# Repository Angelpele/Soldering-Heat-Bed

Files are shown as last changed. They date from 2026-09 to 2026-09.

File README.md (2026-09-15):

# PCB Heated Soldering Bed

<p align="center">
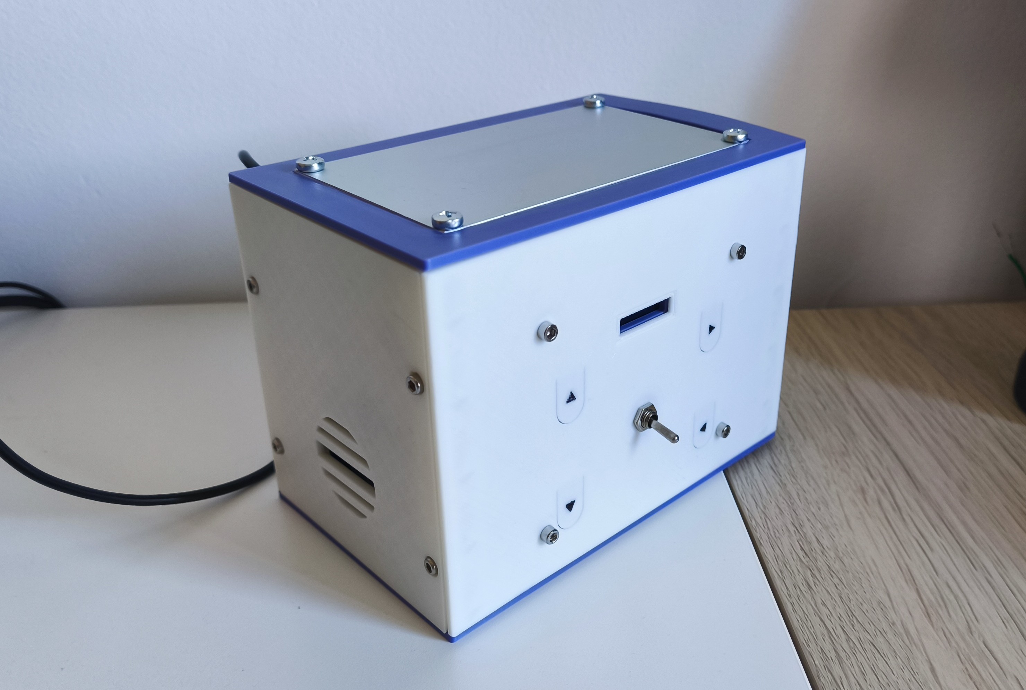
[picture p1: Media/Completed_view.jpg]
Finished heated soldering bed
  
</p>

Custom PCB based heating bed for PCB assembly and solder reflow.

The system uses an Arduino Nano to control a relay that powers a resistive heating plate, monitor temperature with an NTC thermistor, control a cooling fan, and provide a simple OLED interface.

Different buttons provide the user an easy way to navigate through the different menus available in the screen. The reflow profile can be modified, create a new one, power the fan or leave it in automatic mode... The main lever powers the heating element, initiating the reflow process. 

To avoid melting the internals, the heating element was secured with 4 x M4 bolts capable of disipating the heat to the lower part of the assembly. The main structure consists of 6 panels total, secured together with screws and threaded inserts.

---

## Features

| Feature | Description |
|---|---|
| Controller | Arduino Nano |
| Heater | 220 V heating element |
| Temperature sensor | NTC thermistor |
| Heater control | Relay |
| Cooling | 12 V fan + N-MOSFET |
| Display | 0.91" 128×32 I2C OLED |
| User input | 4 buttons + safety lever |
| Audio | Buzzer |
| Modes | Manual heating / Reflow |
| Reflow profile | Sn63Pb37 |
| Temperature range | 30–230 °C |
| Temperature ramp | 1 °C/s |

---

## Hardware

### Components

| Component | Reference | Specification |
|---|---|---|
| Arduino Nano | U101 | Main controller |
| Heating element | Heater | 12 V |
| Relay | R101 | 5 V |
| NTC thermistor | TH101 | Temperature measurement |
| MOSFET | Q101 | N-channel |
| Fan | M101 | 12 V |
| OLED | OLED_0.91 | 128×32, I2C |
| Buzzer | BZ101 | Audio indication |
| Transformer | T1 | 220 V AC → 12 V |
| Main switch | SW1 | Power switch |
| BUT1–BUT4 | — | User controls |
| LEVER | — | Safety input |
| R101 | — | 100 kΩ |
| R102 | — | 100 Ω |
| R103 | — | 1 kΩ |
| R104 | — | — |

---

## Schematic & Wiring

<table>
<tr>
<td width="50%" align="center" valign="top">

<b>Schematic</b><br><br>

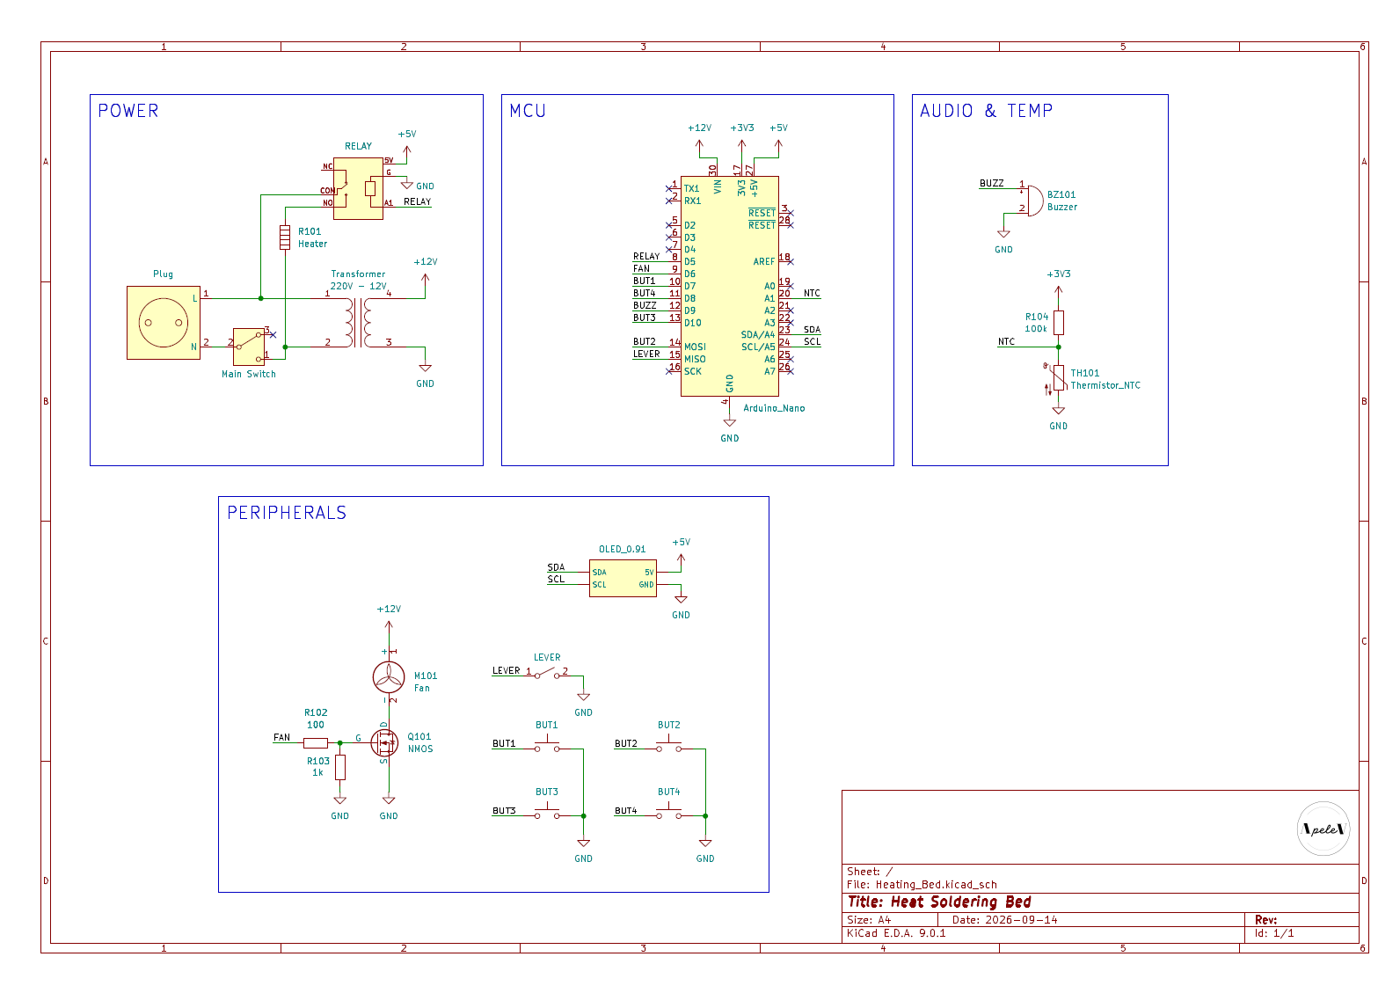
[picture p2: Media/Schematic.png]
Heating bed schematic


</td>

<td width="50%" align="center" valign="top">

<b>Internals / Wiring</b><br><br>

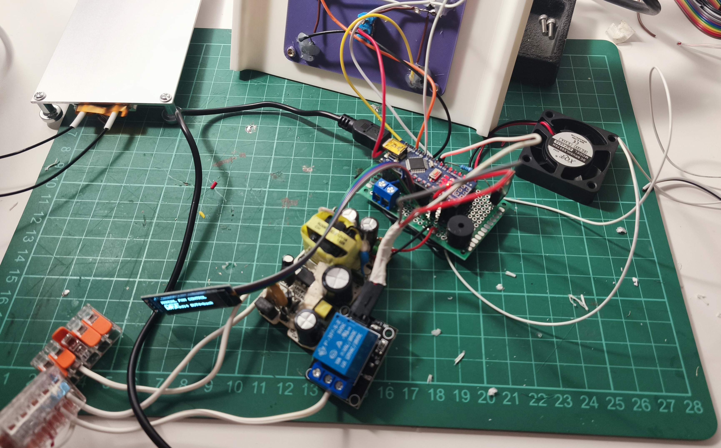
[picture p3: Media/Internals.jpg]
Heating bed wiring


</td>
</tr>
</table>

---

## Reflow Profile

| Stage | Target | Duration |
|---|---:|---:|
| Stage 1 | 150 °C | 60 s |
| Stage 2 | 180 °C | 60 s |
| Stage 3 | 210 °C | 30 s |

Setpoint ramp: **1 °C/s**

---

## Reflow Test

<p align="center">
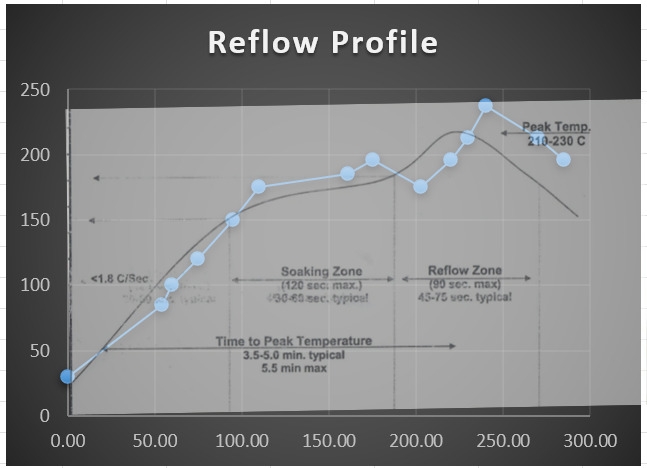
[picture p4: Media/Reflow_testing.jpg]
Theoretical vs real reflow temperature profile
  
</p>

| Profile | Description |
|---|---|
| Theory | Target temperature profile |
| Real | Temperature measured during the test |

The difference is mainly caused by thermal inertia, heater power, heat losses, sensor position, and control response.

---

## Temperature Control

| Parameter | Value |
|---|---:|
| Series resistor | 100 kΩ |
| Nominal resistance | 75 kΩ |
| Nominal temperature | 20 °C |
| Beta coefficient | 4092 |

```cpp
const float SERIES_RESISTOR      = 100000.0;
const float NOMINAL_RESISTANCE   = 75000.0;
const float NOMINAL_TEMPERATURE  = 20.0;
const float B_COEFFICIENT        = 4092.0;

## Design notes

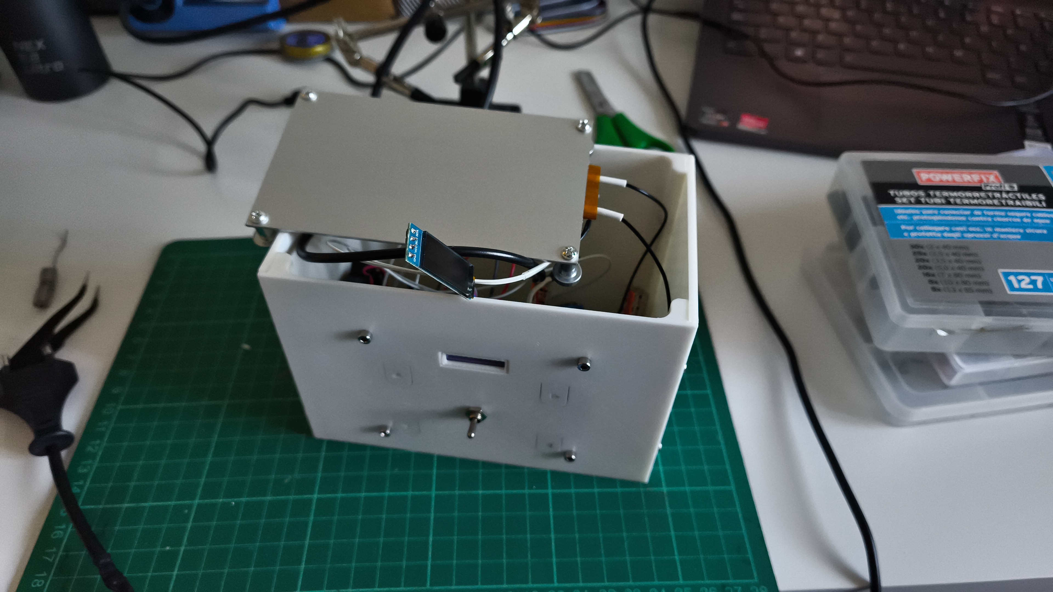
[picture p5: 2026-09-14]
Media/Top_opened.jpeg

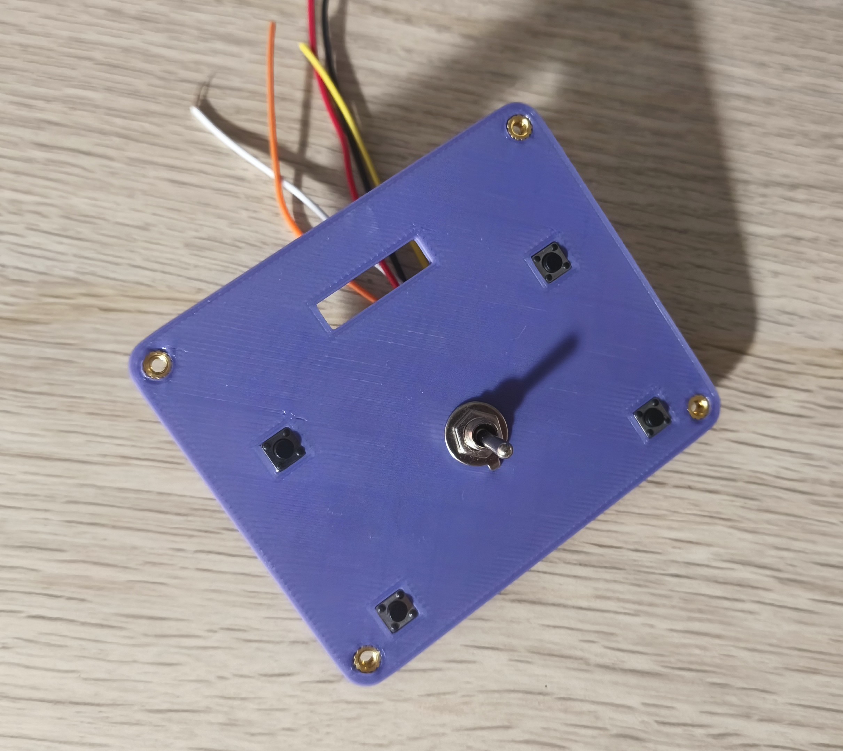
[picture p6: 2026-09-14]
Media/Button_panel.jpg

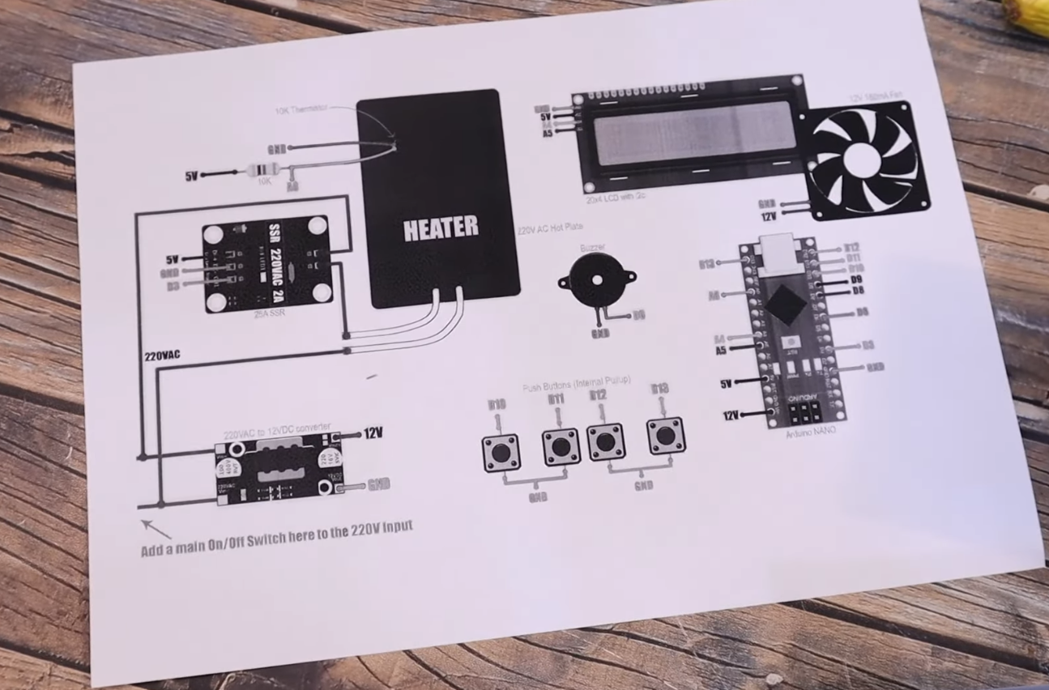
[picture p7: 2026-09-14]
Media/Screenshot 2026-09-02 192525.png

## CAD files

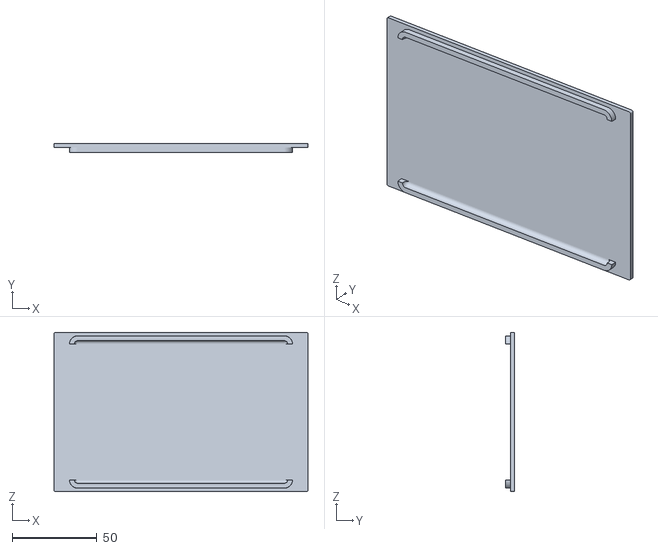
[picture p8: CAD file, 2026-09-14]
Mechanical/Bottom Plate v3.stl
150.0 x 5.50 x 94.2

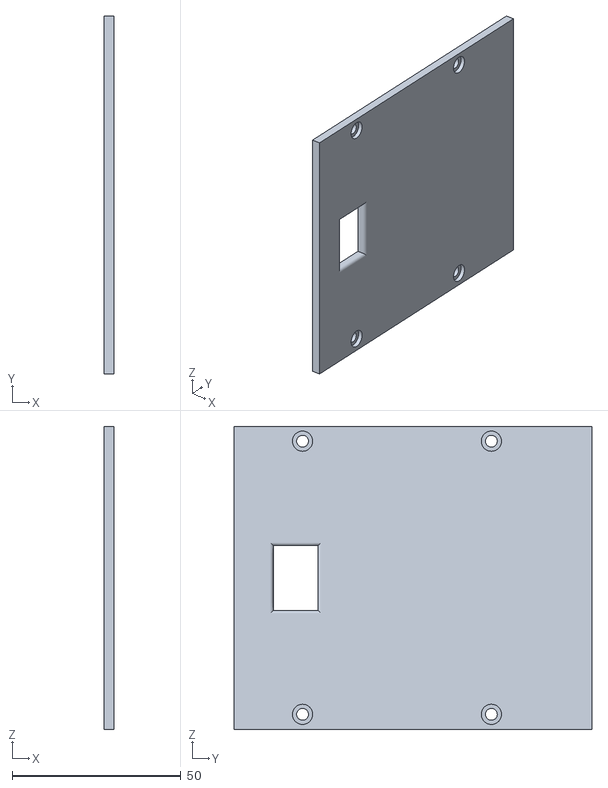
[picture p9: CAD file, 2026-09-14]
Mechanical/Side Wall v6.stl
3.00 x 106.1 x 89.8

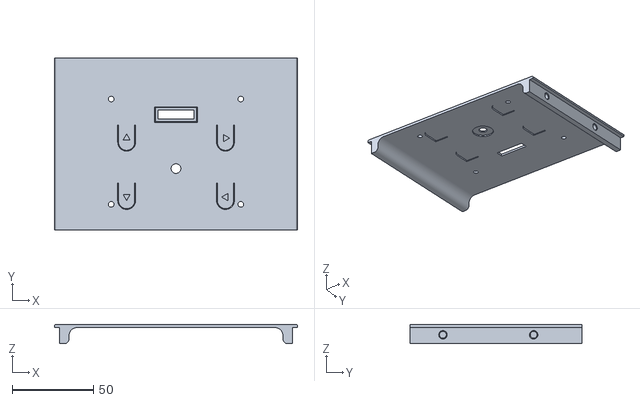
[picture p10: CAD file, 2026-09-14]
Mechanical/Front Wall.stl
150.0 x 106.1 x 12.0

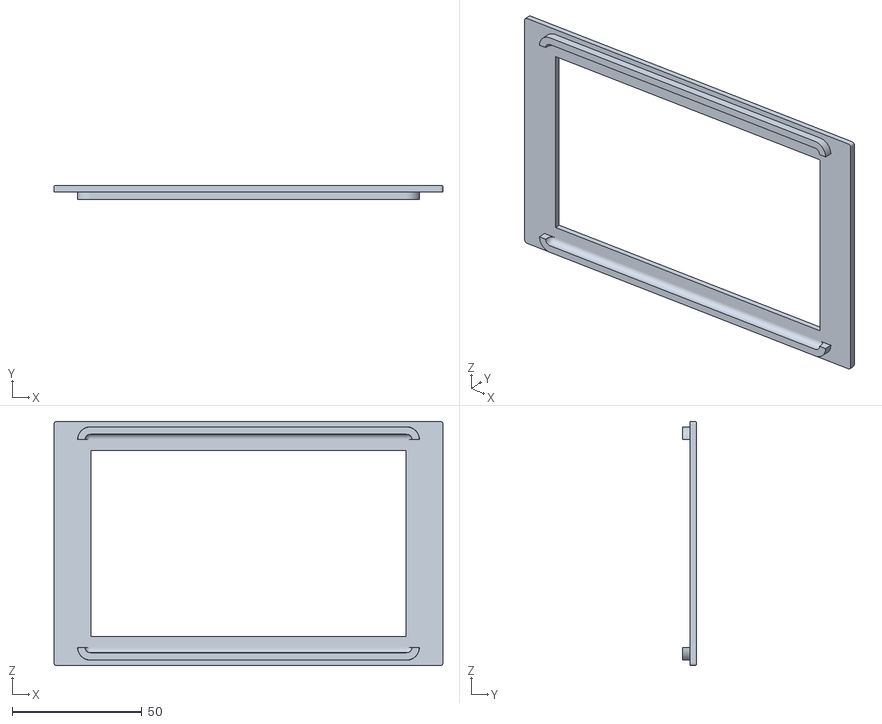
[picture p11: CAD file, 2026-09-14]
Mechanical/Top Cover v6.stl
150.0 x 5.50 x 94.2

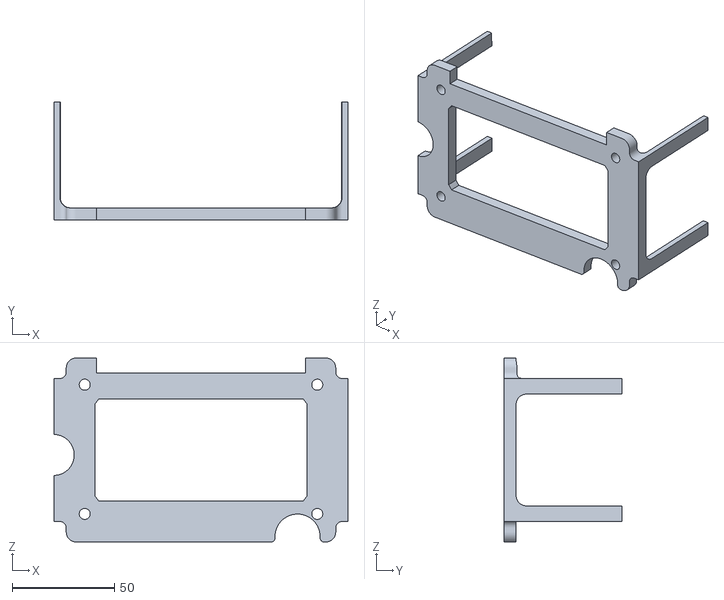
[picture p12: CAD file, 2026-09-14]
Mechanical/Middle_Plate.stl
143.7 x 57.8 x 90.0

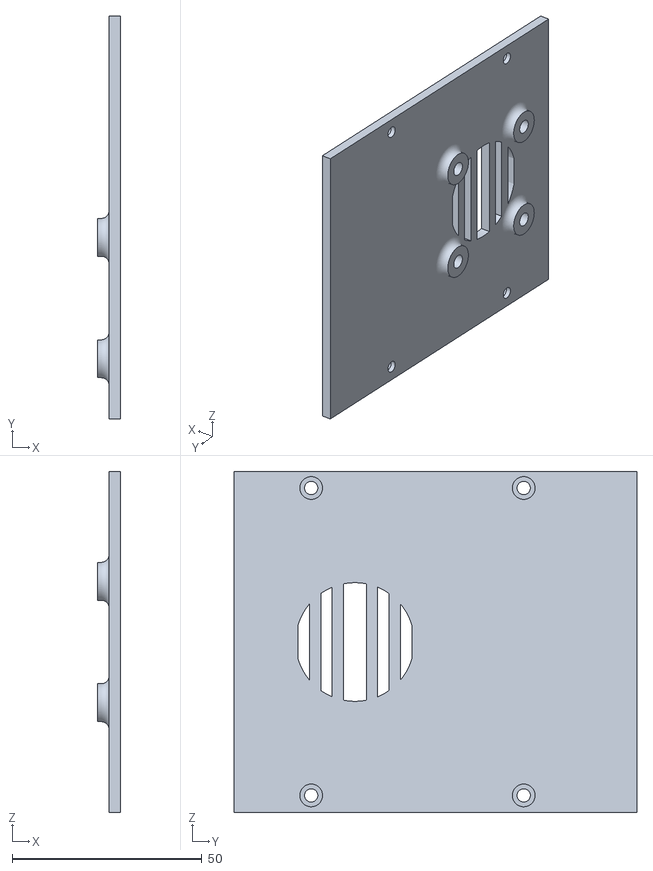
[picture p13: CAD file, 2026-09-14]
Mechanical/Side Wall Fan v3.stl
6.00 x 106.1 x 89.8

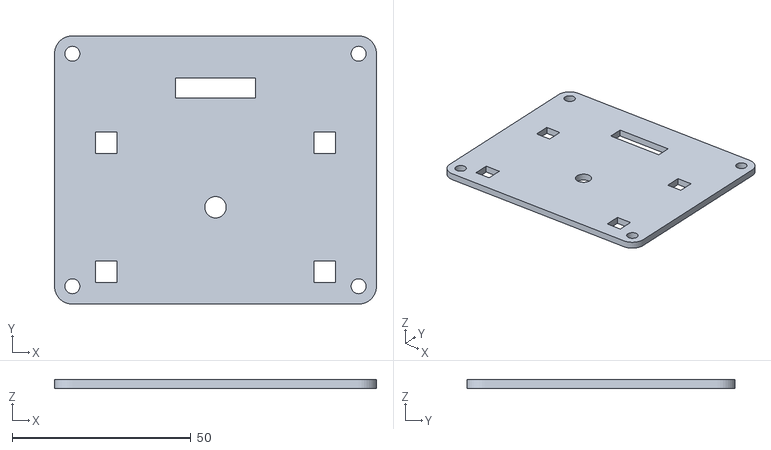
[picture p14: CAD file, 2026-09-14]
Mechanical/Button_Panel.stl
90.0 x 75.0 x 2.50

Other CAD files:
Mechanical/Back Wall v6.stl

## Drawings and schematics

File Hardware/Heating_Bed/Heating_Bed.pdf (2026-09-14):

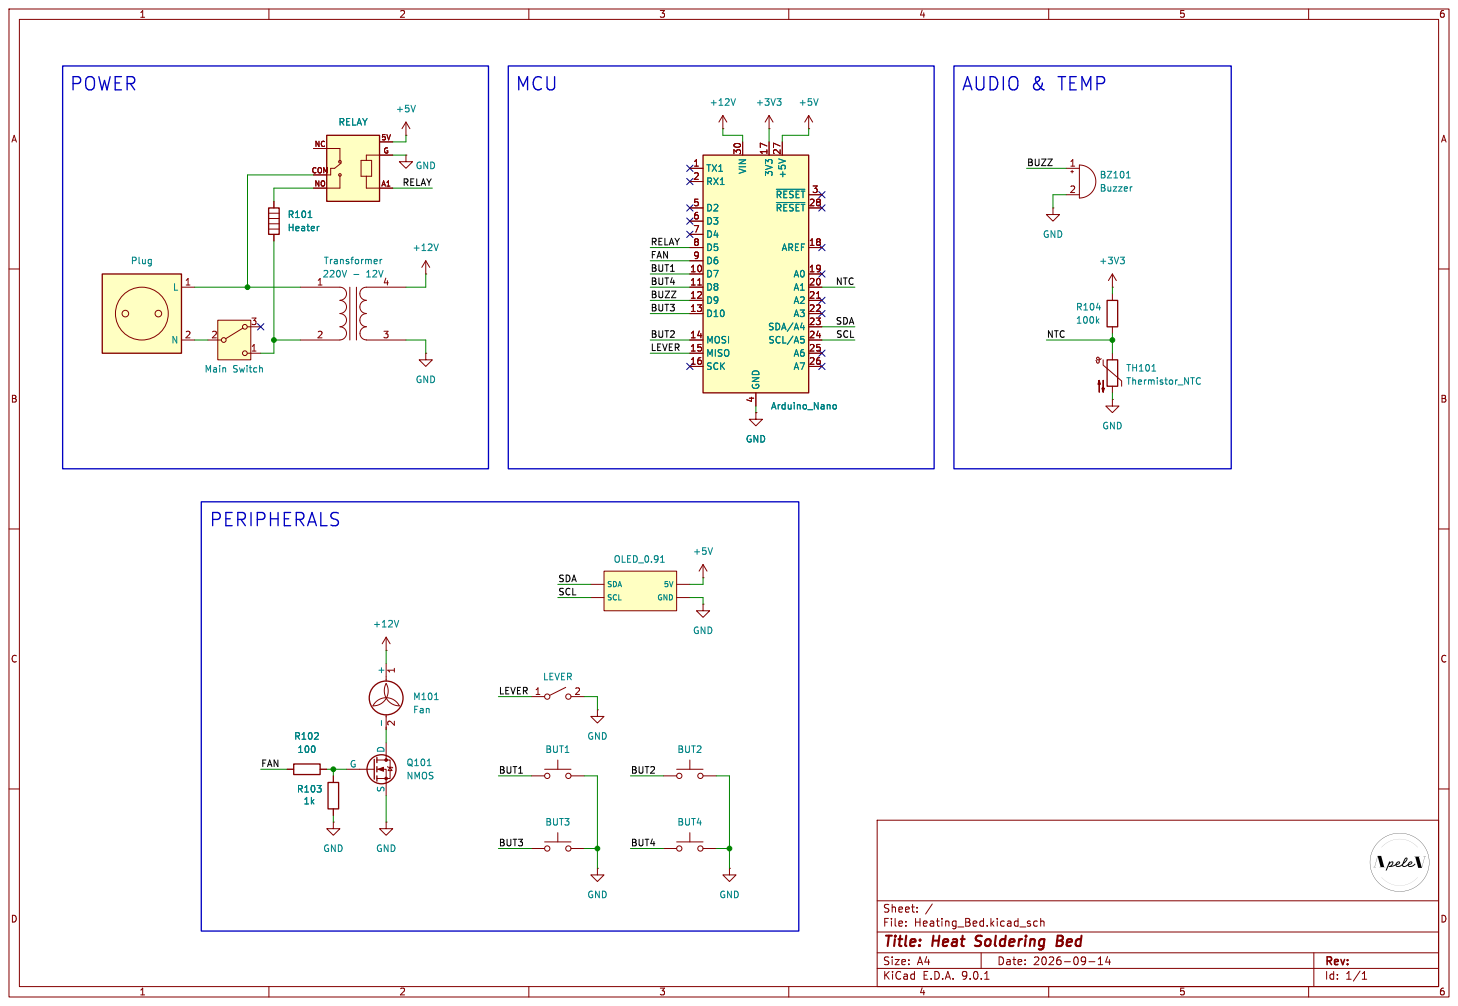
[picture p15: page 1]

File: Heating_Bed.kicad_sch Sheet: /
Id: 1/1 Title: Heat Soldering Bed

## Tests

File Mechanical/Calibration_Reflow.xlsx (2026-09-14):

Time | Temperature
0.00 | 30
54.00 | 85
60.00 | 100
75.00 | 120
95.00 | 150
110.00 | 175
161.00 | 185
175.00 | 196
203.00 | 175
220.00 | 196
230.00 | 213
240.00 | 237
270.00 | 213
285.00 | 196
297.00 | 185
311.00 | 175
320.00 | 168
337.00 | 156
354.00 | 147
372.00 | 140
382.00 | 134
392.00 | 129
404.00 | 124
453.00 | 115
480.00 | 100

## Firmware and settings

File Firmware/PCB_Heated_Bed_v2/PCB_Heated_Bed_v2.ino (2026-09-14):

#include <Wire.h>
#include <Adafruit_GFX.h>
#include <Adafruit_SSD1306.h>
#include <EEPROM.h>

// =====================================================
// PINS
// =====================================================

#define FAN_PIN     6
#define RELAY_PIN   5
#define BUZZER_PIN  9
#define BUT1_PIN    7
#define BUT2_PIN    11
#define BUT3_PIN    10
#define BUT4_PIN    8
#define LEVER_PIN   12

#define THERMISTOR_PIN A1

// OLED 0.91" -> 128x32
#define SCREEN_WIDTH  128
#define SCREEN_HEIGHT 32

#define OLED_RESET    -1
#define OLED_ADDRESS  0x3C

Adafruit_SSD1306 display(SCREEN_WIDTH, SCREEN_HEIGHT, &Wire, OLED_RESET);

// =====================================================
// THERMISTOR (NTC) CONFIG
// =====================================================

const float SERIES_RESISTOR      = 100000.0; // Ohms
const float NOMINAL_RESISTANCE   = 75000.0; // Ohms at 30C
const float NOMINAL_TEMPERATURE  = 20.0;    // C
const float B_COEFFICIENT        = 4092.0;
const int   ADC_MAX              = 1023;

// =====================================================
// GENERAL CONFIG
// =====================================================

const unsigned long DEBOUNCE_DELAY   = 30;    // ms
const unsigned long BUZZER_TIME      = 100;   // ms beep length
const unsigned long WARNING_TIME     = 5000;  // ms lever-on warning before heating

const int MIN_TARGET_TEMP = 30;
const int MAX_TARGET_TEMP = 230;

// =====================================================
// TIME-PROPORTIONING & RAMP CONTROL (OVERSHOOT FIX)
// =====================================================

const unsigned long HEAT_WINDOW_MS = 4000;  // length of one PWM cycle
const float HEAT_DUTY_MAX  = 0.35f;         // REDUCED: hard cap on ON-fraction due to huge thermal mass
const float HEAT_PROP_BAND = 30.0f;         // INCREASED: tapers off heat earlier to prevent overshoot

// Ramping restricts how fast the target temperature climbs so the thermistor can keep up
const float RAMP_RATE_C_PER_SEC = 1.0f;     // Complies with the <1.8 C/Sec limit on the graph

unsigned long heatWindowStart = 0;
unsigned long heatOnTime      = 0;
unsigned long lastRampTime    = 0;
float dynamicSetpoint         = 25.0f;      // Slowly climbs to the actual target

// =====================================================
// REFLOW PROFILE DATA
// =====================================================

struct ProfileStage {
  int targetTemp; // C
  int duration;   // seconds, 0 = hold indefinitely
};

#define MAX_STAGES 3

bool isReflowProfile = false;
int currentProfileStages = 1;
int currentStageIndex = 0;
ProfileStage activeProfile[MAX_STAGES];

// Based on the handwritten notes and Kester graph
const ProfileStage KESTER_PROFILE[MAX_STAGES] = {
  { 150, 60 },  // Preheat / Soak Start
  { 180, 60 },  // Soak End (Notes say ~58s)
  { 210, 30 }   // Reflow Peak
};

// =====================================================
// EEPROM DATA
// =====================================================

struct Settings {
  uint8_t  magic;
  int      targetTemp; // Saved manual bake temperature
};

const uint8_t SETTINGS_MAGIC = 0xA6; // Changed to force reset with new struct
Settings settings;

// =====================================================
// INPUT DEBOUNCING (buttons + lever)
// =====================================================

struct DebouncedInput {
  uint8_t pin;
  bool activeLow;
  bool stableState;
  bool lastReading;
  unsigned long lastChangeTime;
};

DebouncedInput but1  = { BUT1_PIN,  true,  false, false, 0 };
DebouncedInput but2  = { BUT2_PIN,  true,  false, false, 0 };
DebouncedInput but3  = { BUT3_PIN,  true,  false, false, 0 };
DebouncedInput but4  = { BUT4_PIN,  true,  false, false, 0 };
DebouncedInput lever = { LEVER_PIN, false, false, false, 0 };

bool updateInput(DebouncedInput &in) {
  bool raw = digitalRead(in.pin);
  bool reading = in.activeLow ? !raw : raw;

  if (reading != in.lastReading) {
    in.lastChangeTime = millis();
  }

  bool changed = false;
  if ((millis() - in.lastChangeTime) > DEBOUNCE_DELAY) {
    if (reading != in.stableState) {
      in.stableState = reading;
      changed = true;
    }
  }

  in.lastReading = reading;
  return changed;
}

// =====================================================
// UI STATE MACHINE
// =====================================================

enum UIState {
  UI_TOP,
  UI_FAN_EDIT,
  UI_TEMP_EDIT
};

enum TopScreen {
  SCREEN_HOME = 0,
  SCREEN_FAN,
  SCREEN_TEMP,
  SCREEN_REFLOW,
  SCREEN_COUNT
};

UIState  uiState    = UI_TOP;
int      screenIndex = SCREEN_HOME;

enum FanMode { FAN_AUTO = 0, FAN_FORCED_ON, FAN_FORCED_OFF };
const char *fanModeName(FanMode m);

FanMode fanMode = FAN_AUTO;
FanMode fanModeEditBuffer = FAN_AUTO;
int tempEditBuffer = 50;

// =====================================================
// BED (RELAY) CONTROL STATE MACHINE
// =====================================================

enum BedState { BED_IDLE, BED_WARNING, BED_RAMPING, BED_SOAKING, BED_COOLING, BED_DONE };
BedState bedState = BED_IDLE;

unsigned long warningStartTime = 0;
unsigned long soakStartTime    = 0;
int  lastWarningBeepSecond = -1;

bool fanOnState   = false;
bool relayOnState = false;
float currentTempC = 25.0;

// =====================================================
// NON-BLOCKING BUZZER
// =====================================================

bool buzzerActive = false;
unsigned long buzzerOffTime = 0;

void buzzerStart(unsigned long durationMs) {
  analogWrite(BUZZER_PIN, 128);
  buzzerActive = true;
  buzzerOffTime = millis() + durationMs;
}

void buzzerUpdate() {
  if (buzzerActive && millis() >= buzzerOffTime) {
    analogWrite(BUZZER_PIN, 0);
    buzzerActive = false;
  }
}

// =====================================================
// EEPROM HELPERS
// =====================================================

void loadDefaultSettings() {
  settings.magic = SETTINGS_MAGIC;
  settings.targetTemp = 60; // Safe default for manual mode
}

void loadSettings() {
  EEPROM.get(0, settings);
  if (settings.magic != SETTINGS_MAGIC ||
      settings.targetTemp < MIN_TARGET_TEMP ||
      settings.targetTemp > MAX_TARGET_TEMP) {
    loadDefaultSettings();
    EEPROM.put(0, settings);
  }
}

void saveSettings() {
  EEPROM.put(0, settings);
}

// =====================================================
// THERMISTOR READING
// =====================================================

float readTemperatureC() {
  int raw = analogRead(THERMISTOR_PIN);
  if (raw <= 0) raw = 1;
  if (raw >= ADC_MAX) raw = ADC_MAX - 1;

  float resistance = SERIES_RESISTOR / ((float)ADC_MAX / raw - 1.0);
  float steinhart = resistance / NOMINAL_RESISTANCE;
  steinhart = log(steinhart);
  steinhart /= B_COEFFICIENT;
  steinhart += 1.0 / (NOMINAL_TEMPERATURE + 273.15);
  steinhart = 1.0 / steinhart;
  steinhart -= 273.15;
  return steinhart;
}

// =====================================================
// ACTUATORS
// =====================================================

void setFan(bool on) {
  fanOnState = on;
  digitalWrite(FAN_PIN, on ? HIGH : LOW);
}

void setRelay(bool on) {
  relayOnState = on;
  digitalWrite(RELAY_PIN, on ? HIGH : LOW);
}

void updateFanControl() {
  switch (fanMode) {
    case FAN_FORCED_ON:  setFan(true); break;
    case FAN_FORCED_OFF: setFan(false); break;
    case FAN_AUTO:
    default:
      // Auto fan logic during cooling or if current temp is highly over target
      if (bedState == BED_COOLING) {
          setFan(true);
      } else if (bedState == BED_IDLE || bedState == BED_DONE) {
          setFan(currentTempC > 50.0);
      } else {
          setFan(false); // keep fan off while actively heating
      }
      break;
  }
}

// =====================================================
// PROFILE ACTIVATION
// =====================================================

void applyManualTarget(int newTargetTemp) {
  currentProfileStages = 1;
  activeProfile[0] = { newTargetTemp, 0 }; // 0 duration = hold indefinitely
  isReflowProfile = false;
  bedState = BED_IDLE;
}

void applyReflowProfile() {
  currentProfileStages = MAX_STAGES;
  for(int i=0; i<MAX_STAGES; i++) {
    activeProfile[i] = KESTER_PROFILE[i];
  }
  isReflowProfile = true;
  bedState = BED_IDLE;
}

// =====================================================
// CONTROL LOGIC (WITH SETPOINT RAMPING)
// =====================================================

void updateHeatOutput(float targetTemp) {
  unsigned long now = millis();
  unsigned long elapsedInWindow = now - heatWindowStart;

  if (elapsedInWindow >= HEAT_WINDOW_MS) {
    float error = targetTemp - currentTempC;
    // Duty cycle calculation
    float duty = constrain(error / HEAT_PROP_BAND, 0.0f, 1.0f) * HEAT_DUTY_MAX;
    heatOnTime = (unsigned long)(duty * HEAT_WINDOW_MS);
    heatWindowStart = now;
    elapsedInWindow = 0;
  }

  setRelay(elapsedInWindow < heatOnTime);
}

void updateBedControl() {
  bool leverChanged = updateInput(lever);
  (void)leverChanged;

  if (!lever.stableState) {
    if (bedState != BED_IDLE) {
      setRelay(false);
      bedState = BED_IDLE;
    }
    return;
  }

  switch (bedState) {

    case BED_IDLE:
      bedState = BED_WARNING;
      warningStartTime = millis();
      lastWarningBeepSecond = -1;
      break;

    case BED_WARNING: {
      unsigned long elapsed = millis() - warningStartTime;
      int currentSecond = elapsed / 1000;
      if (currentSecond != lastWarningBeepSecond) {
        lastWarningBeepSecond = currentSecond;
        buzzerStart(BUZZER_TIME);
      }
      if (elapsed >= WARNING_TIME) {
        bedState = BED_RAMPING;
        currentStageIndex = 0;
        dynamicSetpoint = currentTempC; // Initialize soft-start at current room temp
        lastRampTime = millis();
        heatWindowStart = millis();
      }
      break;
    }

    case BED_RAMPING: {
      // 1. Advance the dynamic setpoint (Soft Start)
      unsigned long now = millis();
      float dt_sec = (now - lastRampTime) / 1000.0f;
      lastRampTime = now;
      
      dynamicSetpoint += RAMP_RATE_C_PER_SEC * dt_sec;
      
      int stageTarget = activeProfile[currentStageIndex].targetTemp;
      if (dynamicSetpoint > stageTarget) {
        dynamicSetpoint = stageTarget; // Cap at the target for this stage
      }

      // 2. Control heat based on the *dynamic* setpoint, not the final target
      updateHeatOutput(dynamicSetpoint);

      // 3. Move to soak when actual temperature reaches the stage target
      if (currentTempC >= stageTarget) {
        if (activeProfile[currentStageIndex].duration > 0) {
          bedState = BED_SOAKING;
          soakStartTime = millis();
        } else {
          // If duration is 0 (Manual mode), stay in ramping/holding indefinitely
          dynamicSetpoint = stageTarget; 
        }
      }
      break;
    }

    case BED_SOAKING:
      // Hold exactly at the stage target
      updateHeatOutput(activeProfile[currentStageIndex].targetTemp);

      if (millis() - soakStartTime >= (unsigned long)activeProfile[currentStageIndex].duration * 1000UL) {
        currentStageIndex++;
        if (currentStageIndex >= currentProfileStages) {
          bedState = BED_COOLING; // All stages complete
        } else {
          bedState = BED_RAMPING; // Move to next heating stage
          lastRampTime = millis();
        }
      }
      break;

    case BED_COOLING:
      setRelay(false);
      if (currentTempC <= 50.0) {
        bedState = BED_DONE;
        buzzerStart(500); // Long beep to indicate done
      }
      break;

    case BED_DONE:
      setRelay(false);
      break;
  }
}

// =====================================================
// BUTTON HANDLING / NAVIGATION
// =====================================================

void handleTopNavigation(bool p1, bool p2, bool p3, bool p4) {
  if (p1) screenIndex = (screenIndex + SCREEN_COUNT - 1) % SCREEN_COUNT;
  if (p2) screenIndex = (screenIndex + 1) % SCREEN_COUNT;

  if (p3) {
    switch (screenIndex) {
      case SCREEN_FAN:
        fanModeEditBuffer = fanMode;
        uiState = UI_FAN_EDIT;
        break;
      case SCREEN_TEMP:
        tempEditBuffer = settings.targetTemp;
        uiState = UI_TEMP_EDIT;
        break;
      case SCREEN_REFLOW:
        applyReflowProfile(); // Instantly selects the reflow profile
        buzzerStart(BUZZER_TIME);
        screenIndex = SCREEN_HOME;
        break;
      case SCREEN_HOME:
      default:
        break; 
    }
  }

  if (p4) {
    screenIndex = SCREEN_HOME;
  }
}

void handleFanEdit(bool p1, bool p2, bool p3, bool p4) {
  if (p1) fanModeEditBuffer = (FanMode)((fanModeEditBuffer + 1) % 3);
  if (p2) fanModeEditBuffer = (FanMode)((fanModeEditBuffer + 2) % 3);
  if (p3) {
    fanMode = fanModeEditBuffer;
    buzzerStart(BUZZER_TIME);
    uiState = UI_TOP;
  }
  if (p4) uiState = UI_TOP;
}

void handleTempEdit(bool p1, bool p2, bool p3, bool p4) {
  if (p1) tempEditBuffer = min(tempEditBuffer + 1, MAX_TARGET_TEMP);
  if (p2) tempEditBuffer = max(tempEditBuffer - 1, MIN_TARGET_TEMP);
  if (p3) {
    settings.targetTemp = tempEditBuffer;
    saveSettings();
    applyManualTarget(settings.targetTemp); // Sets manual mode
    buzzerStart(BUZZER_TIME);
    uiState = UI_TOP;
  }
  if (p4) uiState = UI_TOP;
}

void handleButtons() {
  bool c1 = updateInput(but1);
  bool c2 = updateInput(but2);
  bool c3 = updateInput(but3);
  bool c4 = updateInput(but4);

  bool p1 = c1 && but1.stableState;
  bool p2 = c2 && but2.stableState;
  bool p3 = c3 && but3.stableState;
  bool p4 = c4 && but4.stableState;

  if (!(p1 || p2 || p3 || p4)) return;

  switch (uiState) {
    case UI_TOP:       handleTopNavigation(p1, p2, p3, p4); break;
    case UI_FAN_EDIT:  handleFanEdit(p1, p2, p3, p4);       break;
    case UI_TEMP_EDIT: handleTempEdit(p1, p2, p3, p4);      break;
  }
}

// =====================================================
// DISPLAY
// =====================================================

const char *fanModeName(FanMode m) {
  switch (m) {
    case FAN_FORCED_ON:  return "ON";
    case FAN_FORCED_OFF: return "OFF";
    case FAN_AUTO:
    default:              return "AUTO";
  }
}

void drawLogo() {
  display.clearDisplay();
  display.setTextColor(SSD1306_WHITE);
  display.drawRect(2, 2, SCREEN_WIDTH - 4, SCREEN_HEIGHT - 4, SSD1306_WHITE);
  display.setTextSize(1);
  display.setCursor(14, 4);
  display.print("PCB HEATED BED");
  display.setCursor(30, 18);
  display.print("v3  booting...");
  display.display();
}

void drawHome() {
  display.drawRoundRect(0, 0, SCREEN_WIDTH, SCREEN_HEIGHT, 4, SSD1306_WHITE);

  display.setTextSize(1);
  display.setCursor(8, 3);
  
  // Show Current Mode and Status
  if (isReflowProfile) {
    if (bedState == BED_RAMPING)        display.print("REFLOW: RAMPING");
    else if (bedState == BED_SOAKING)   display.print("REFLOW: SOAKING");
    else if (bedState == BED_COOLING)   display.print("REFLOW: COOLING");
    else if (bedState == BED_DONE)      display.print("REFLOW: DONE");
    else                                display.print("READY: REFLOW SOLDER");
  } else {
    display.print("READY: MANUAL BAKE");
  }
  display.drawFastHLine(6, 12, SCREEN_WIDTH - 12, SSD1306_WHITE);

  char buf[8];
  dtostrf(currentTempC, 4, 1, buf);
  display.setTextSize(2);
  display.setCursor(28, 16);
  display.print(buf);
  display.print("C");
}

void drawFanScreen() {
  display.setCursor(0, 0);
  display.print("MANUAL FAN CONTROL");
  display.setCursor(0, 8);
  display.setTextSize(2);
  display.print(fanModeName(fanMode));
  display.setTextSize(1);
  display.setCursor(0, 24);
  display.print("BUT3=edit BUT4=back");
}

void drawFanEditScreen() {
  display.setCursor(0, 0);
  display.print("SET FAN MODE");
  display.setCursor(0, 8);
  display.setTextSize(2);
  display.print(fanModeName(fanModeEditBuffer));
  display.setTextSize(1);
  display.setCursor(0, 24);
  display.print("3=OK  4=cancel");
}

void drawTempScreen() {
  display.setCursor(0, 0);
  display.print("MANUAL TARGET TEMP");
  display.setCursor(0, 12);
  display.setTextSize(2);
  display.print(settings.targetTemp);
  display.print("C");
  display.setTextSize(1);
  display.setCursor(70, 20);
  display.print("Now:");
  display.print((int)currentTempC);
}

void drawTempEditScreen() {
  display.setCursor(0, 0);
  display.print("SET MANUAL TEMP");
  display.setCursor(0, 8);
  display.setTextSize(2);
  display.print(tempEditBuffer);
  display.print("C");
  display.setTextSize(1);
  display.setCursor(0, 24);
  display.print("1=+ 2=- 3=OK 4=X");
}

void drawReflowScreen() {
  display.setCursor(0, 0);
  display.print("REFLOW PROFILE");
  display.setCursor(0, 10);
  display.print("Kester Sn63Pb37");
  display.setCursor(0, 24);
  display.print("BUT3=Select BUT4=Back");
}

void updateDisplay() {
  display.clearDisplay();
  display.setTextColor(SSD1306_WHITE);
  display.setTextSize(1);

  if (uiState == UI_TOP) {
    switch (screenIndex) {
      case SCREEN_HOME:   drawHome();        break;
      case SCREEN_FAN:    drawFanScreen();   break;
      case SCREEN_TEMP:   drawTempScreen();  break;
      case SCREEN_REFLOW: drawReflowScreen();break;
    }
  } else {
    switch (uiState) {
      case UI_FAN_EDIT:  drawFanEditScreen();  break;
      case UI_TEMP_EDIT: drawTempEditScreen(); break;
      default: break;
    }
  }

  if (bedState == BED_WARNING) {
    unsigned long remaining = WARNING_TIME - (millis() - warningStartTime);
    unsigned long secondsLeft = (remaining / 1000) + 1;
    char buf[16];
    snprintf(buf, sizeof(buf), "BED ON IN %lus", secondsLeft);

    const int boxX = 4;
    const int boxY = 1;
    const int boxW = SCREEN_WIDTH - (boxX * 2);
    const int boxH = 12;

    display.fillRect(boxX, boxY, boxW, boxH, SSD1306_BLACK);
    display.drawRect(boxX, boxY, boxW, boxH, SSD1306_WHITE);

    int16_t x1, y1;
    uint16_t textW, textH;
    display.setTextSize(1);
    display.getTextBounds(buf, 0, 0, &x1, &y1, &textW, &textH);
    int textX = boxX + (boxW - (int)textW) / 2;
    int textY = boxY + (boxH - (int)textH) / 2 + 1;

    display.setCursor(textX, textY);
    display.print(buf);
  }

  display.display();
}

// =====================================================
// SETUP & LOOP
// =====================================================

void setup() {
  pinMode(FAN_PIN, OUTPUT);
  pinMode(RELAY_PIN, OUTPUT);
  pinMode(BUZZER_PIN, OUTPUT);

  pinMode(BUT1_PIN, INPUT_PULLUP);
  pinMode(BUT2_PIN, INPUT_PULLUP);
  pinMode(BUT3_PIN, INPUT_PULLUP);
  pinMode(BUT4_PIN, INPUT_PULLUP);
  pinMode(LEVER_PIN, INPUT_PULLUP);

  digitalWrite(FAN_PIN, LOW);
  digitalWrite(RELAY_PIN, LOW);
  analogWrite(BUZZER_PIN, 0);

  if (!display.begin(SSD1306_SWITCHCAPVCC, OLED_ADDRESS)) {
    while (true) { digitalWrite(RELAY_PIN, LOW); delay(1000); }
  }

  drawLogo();
  delay(2000);

  loadSettings();
  
  // Default to manual bake state on boot
  applyManualTarget(settings.targetTemp); 
  currentTempC = readTemperatureC();
  updateDisplay();
}

void loop() {
  currentTempC = readTemperatureC();

  handleButtons();
  updateFanControl();
  updateBedControl();
  buzzerUpdate();
  updateDisplay();

  delay(20);
}

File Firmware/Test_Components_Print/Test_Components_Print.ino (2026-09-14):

#include <Wire.h>
#include <Adafruit_GFX.h>
#include <Adafruit_SSD1306.h>

// =====================================================
// PINES
// =====================================================

#define FAN_PIN     6
#define RELAY_PIN   5
#define BUZZER_PIN  9
#define BUT1_PIN    7
#define BUT2_PIN    8
#define BUT3_PIN    10
#define BUT4_PIN    11
#define LEVER_PIN    12

// OLED 0.91" normalmente 128x32
#define SCREEN_WIDTH  120
#define SCREEN_HEIGHT 32

#define OLED_RESET    -1
#define OLED_ADDRESS  0x3C

Adafruit_SSD1306 display(SCREEN_WIDTH, SCREEN_HEIGHT, &Wire, OLED_RESET);

// =====================================================
// CONFIGURACIÓN
// =====================================================

const unsigned long FAN_INTERVAL = 5000;  // 5 segundos
const unsigned long BUZZER_TIME   = 150;   // duración pitido

bool fanState = false;
bool relayState = false;

unsigned long lastChange = 0;

// =====================================================
// BUZZER PWM
// =====================================================

void buzzerBeep()
{
  // PWM al 50% en D6
  // analogWrite() genera PWM ~490 Hz en Arduino Uno/Nano
  analogWrite(BUZZER_PIN, 128);

  delay(BUZZER_TIME);

  analogWrite(BUZZER_PIN, 0);
}

void readbuttons()
{

}

// =====================================================
// OLED
// =====================================================

void updateDisplay()
{
  unsigned long elapsed = millis() - lastChange;

  unsigned long remaining;

  if (elapsed >= FAN_INTERVAL)
    remaining = 0;
  else
    remaining = (FAN_INTERVAL - elapsed) / 1000 + 1;

  display.clearDisplay();

  display.setTextColor(SSD1306_WHITE);

  // Línea 1
  display.setTextSize(1);
  display.setCursor(0, 0);
  display.print("PCB HEATED BED V2");

  // Línea 2
  display.setTextSize(2);
  display.setCursor(0, 12);

  if (relayState)
    display.print("BED ON");
  else
    display.print("BED OFF");

  // Tiempo
  display.setTextSize(1);
  display.setCursor(85, 19);
  display.print(remaining);
  display.print("s");

  // Línea inferior
  display.setCursor(0, 26);
  display.print("MOSFET:D5  BUZZER:D6");

  display.display();
}

// =====================================================
// SETUP
// =====================================================

void setup()
{
  pinMode(FAN_PIN, OUTPUT);
  pinMode(BUZZER_PIN, OUTPUT);
  pinMode(RELAY_PIN, OUTPUT);

  // Inicialmente ventilador apagado
  digitalWrite(FAN_PIN, LOW);
  analogWrite(BUZZER_PIN, 0);
  digitalWrite(RELAY_PIN, LOW);

  // Inicializar OLED
  if (!display.begin(SSD1306_SWITCHCAPVCC, OLED_ADDRESS))
  {
    // Si la OLED no responde, dejamos el programa aquí
    while (true)
    {
      digitalWrite(BUZZER_PIN, 0);
      delay(1000);
    }
  }

  // Pantalla inicial
  display.clearDisplay();
  display.setTextColor(SSD1306_WHITE);

  display.setTextSize(2);
  display.setCursor(15, 0);
  display.print("PCB Heated Bed V2");

  display.display();

  delay(2000);

  // Estado inicial
  fanState = false;
  relayState = false;
  digitalWrite(FAN_PIN, LOW);
  digitalWrite(RELAY_PIN, LOW);

  lastChange = millis();

  updateDisplay();
}

// =====================================================
// LOOP
// =====================================================

void loop()
{
  unsigned long currentTime = millis();

  // Actualizar OLED continuamente
  updateDisplay();
  readbuttons();

  // ===================================================
  // CAMBIAR FAN CADA 5 SEGUNDOS
  // ===================================================

  if (currentTime - lastChange >= FAN_INTERVAL)
  {
    // Cambiar estado
    fanState = !fanState;

    // Activar/desactivar MOSFET
    digitalWrite(FAN_PIN, fanState ? HIGH : LOW);

    // Pitido
    buzzerBeep();

    // Reiniciar temporizador
    lastChange = millis();

    // Actualizar inmediatamente
    updateDisplay();
  }

  delay(50);
}
